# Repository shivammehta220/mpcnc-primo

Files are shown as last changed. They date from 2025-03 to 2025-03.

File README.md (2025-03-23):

# MPCNC Primo

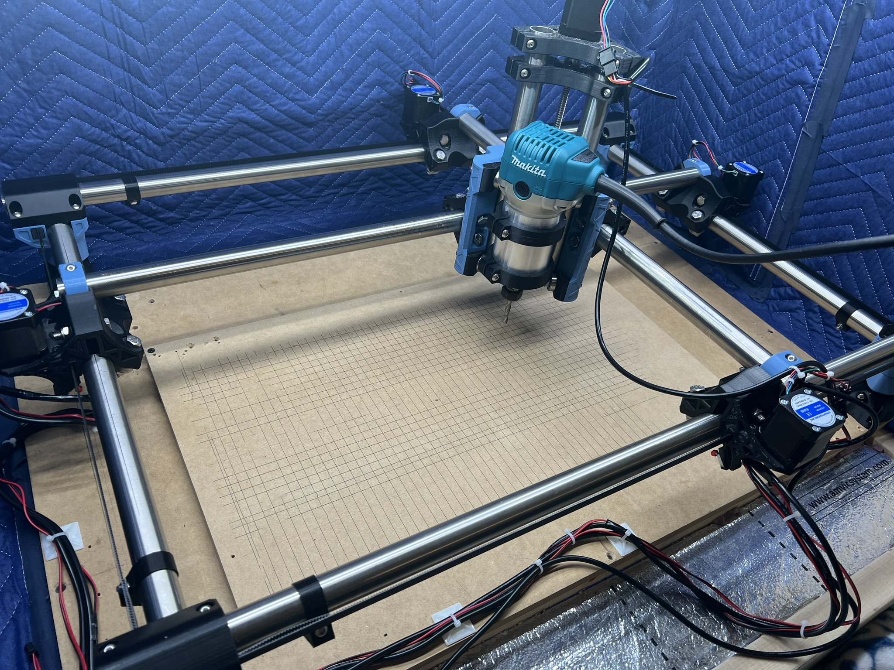
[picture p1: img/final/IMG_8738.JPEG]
Final CNC Build Image

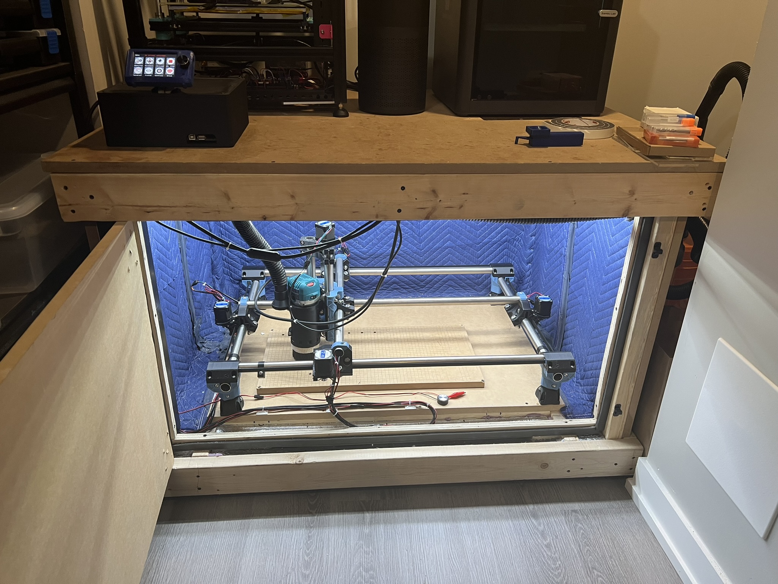
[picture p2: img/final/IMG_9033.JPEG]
Final CNC Build Image


## Table of Contents
- [Description](#description)
- [Table of Resources](#table-of-resources)
- [BOM](#bom)
- [Bits and Settings](#bits-and-settings)
- [Enclosure/Table](#enclosuretable)
- [Dust Management and Dust Shoe](#dust-management-and-dust-shoe)
- [Electronics](#electronics)
- [Build](#build)

---

## Description
This project is my customized version of the [MPCNC Primo](https://www.v1engineering.com/) by V1 Engineering. Within this repository, you will find:
- My unique accessories and modifications.
- Detailed notes on CNC bits and cutting settings.
- A custom-built enclosure/table designed for noise reduction and easy access.
- An electronics box design for convenient maintenance and future upgrades.

The MPCNC (Mostly Printed CNC) is an open-source CNC platform that combines 3D-printed components, off-the-shelf hardware, and commonly available electronics. By customizing the layout, enclosure, and tooling, I’ve tailored this CNC to meet my personal workflow and workspace needs.

---

## Table of Resources
Below is a table of some resources related to this build, including official documentation and helpful community links. Modify or add more links as needed.

| Resource | Link |
|---|---|
| V1 Engineering - MPCNC Primo Docs | [https://www.v1engineering.com/](https://www.v1engineering.com/) |
| Marlin Firmware Repository | [https://github.com/MarlinFirmware/Marlin](https://github.com/MarlinFirmware/Marlin) |
| MPCNC Forum & Community | [https://forum.v1engineering.com/](https://forum.v1engineering.com/) |
| Dust Shoe | [https://grabcad.com/library/mpcnc-primo-dust-shoe-makita-router-1](#) |
| BTT TFT35 v3 TFT Display Case | [https://www.thingiverse.com/thing:4338772](#) |

---

## BOM
Below is the Bill of Materials (BOM) for the MPCNC Primo and the table/enclosure. This includes both the standard hardware from the official MPCNC build, as well as some additional parts I selected for my setup.

| Part | QTY  | Type | Link (if applicable) |
|---|---|---|---|
| Duramic3D PLA+ (Denim Blue & Black) | 2 | Primo Printed Parts | [LINK](https://www.amazon.ca/dp/B08HJ6RML7?ref_=ppx_hzsearch_conn_dt_b_fed_asin_title_3) |
| M8x40mm | 44  | Hardware | [LINK](https://www.amazon.ca/dp/B08595FX34?ref_=ppx_hzsearch_conn_dt_b_fed_asin_title_1&th=1) |
| M8 Locknut | 44 | Hardware | [LINK](https://www.amazon.ca/dp/B0BMX3CBNL?ref_=ppx_hzsearch_conn_dt_b_fed_asin_title_1&th=1) |
| M5x30mm | 60 | Hardware | [LINK](https://www.amazon.ca/iexcell-Thread-Stainless-Socket-Button/dp/B0B5LVMKYY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) |
| M5 Locknut | 60 | Hardware | [LINK](https://www.amazon.ca/dp/B078NNFT93?ref_=ppx_hzsearch_conn_dt_b_fed_asin_title_4&th=1) |
| M3x10mm | 22 | Hardware | [LINK](https://www.amazon.ca/iExcell-Stainless-Socket-Button-Included/dp/B08H2HSPQD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) |
| M2.5x12mm | 8 | Hardware | [LINK](https://www.amazon.ca/iexcell-Thread-Socket-Screws-Finish/dp/B0DDXR7YN7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) |
| NEMA 17 50 oz/in+ | 5 | Electronic  | [LINK](https://www.amazon.ca/dp/B00QEYADRQ?ref_=ppx_hzsearch_conn_dt_b_fed_asin_title_1) |
| Belt GT2 10mm | 1 | Hardware | [LINK](https://www.amazon.ca/dp/B0BYVF35PV?ref_=ppx_hzsearch_conn_dt_b_fed_asin_title_2&th=1) |
| Pulley 16T GT2 10mm (5mm bore) | 4 | Hardware | [LINK](https://www.amazon.ca/dp/B0CD7Y5R7Y?ref_=ppx_hzsearch_conn_dt_b_fed_asin_title_1&th=1) |
| Idler 20T GT2 10mm (5mm bore)  | 8 | Hardware  | [LINK](https://www.amazon.ca/dp/B07P7CF1SZ?ref_=ppx_hzsearch_conn_dt_b_fed_asin_title_2) |
| 24V Power Supply (PSU)  | 1 | Electronic | [LINK](https://www.amazon.ca/dp/B07TTRY6XF?ref_=ppx_hzsearch_conn_dt_b_fed_asin_title_5&th=1) |
| Power Supply Fuse  | 1 | Electronic | [LINK](https://www.amazon.ca/dp/B07Y8DBF7T?ref_=ppx_hzod_title_dt_b_fed_asin_title_0_1) |
| 4-Strand Wires | 1 | Electronic | [LINK](https://www.amazon.ca/dp/B0CLRLJW9K?ref_=ppx_hzsearch_conn_dt_b_fed_asin_title_10&th=1) |
| Bearings | 45 | Hardware | [LINK](https://www.amazon.ca/dp/B00EPNN62M?ref_=ppx_hzsearch_conn_dt_b_fed_asin_title_5&th=1) |
| Leadscrew/Nut | 1 | Hardware | [LINK](https://www.amazon.ca/gp/product/B0981YZ7DN?ie=UTF8&th=1) |
| 5mm to 8mm Coupler  | 1 | Hardware | [LINK](https://www.amazon.ca/gp/product/B011HV6EI2?ie=UTF8&psc=1) |
| SKR Pro | 1 | Electronic  | [LINK](https://www.amazon.ca/BIGTREETECH-high-Frequency-Printer-Control-12864lcd/dp/B07T2RLG2C?th=1) |
| End Stops | 4 | Switch | [LINK](https://www.amazon.ca/dp/B08736NP44?ref_=ppx_hzsearch_conn_dt_b_fed_asin_title_7) |
| BTT TFT | 1 | Electronic  | [LINK](https://www.amazon.ca/BIGTREETECH-Direct-Upgrade-Controller-Motherboard/dp/B07VWGFKLZ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) |
| Makita RT701 | 1 | Router | [LINK](https://www.amazon.ca/gp/product/B00E7D3V4S?ie=UTF8&th=1) |
| Dust Shoe Brush | 1 | Hardware  | [LINK](https://www.amazon.ca/dp/B08M98BRKS?ref_=ppx_hzsearch_conn_dt_b_fed_asin_title_4) |
| M5 Waste Board Nut  | 60 | Hardware | [LINK](https://www.amazon.ca/gp/product/B07D28RKBB?ie=UTF8&th=1) |
| 2x4 | * | Table | [Local Sourcing] |
| 3/4" MDF | * | Table | [Local Sourcing] |
| Hinge | 2 | Table | [Local Sourcing] |
| Door Lock | 2 | Table | [Local Sourcing] |
| Dust Collector | 1 | Collector Unit | [LINK](https://www.amazon.ca/dp/B07XL8X3DG?ref_=ppx_hzsearch_conn_dt_b_fed_asin_title_3&th=1) |
| Dust Bin | 1 | Table | [Local Sourcing] |
| Vacuum | 1 | Table | [LINK](https://www.amazon.ca/Shop-Vac-5985005-Workshop-Gallon-1-Pack/dp/B09FRY4CFV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) |
| Vacuum Hose | 1 | Table | [LINK](https://www.amazon.ca/dp/B00FX36WII?ref_=ppx_hzsearch_conn_dt_b_fed_asin_title_2) |
| Z Endstop | 1 | Electronic | [LINK](https://www.amazon.ca/gp/product/B07Z5X9YHJ?ie=UTF8&psc=1) |

> **Note:** The exact quantities for fasteners (*) will vary based on final frame dimensions and personal enclosure designs.

Below is the BOM of the rails used for my build. The tubes I bought were stainless steel, and I opted for version J (25.4mm). My workspace based off the calculator is 600mm(x) x 330mm(y) x 83mm(z)

| Length (mm/inch) | QTY  | Name | 
|---|---|---|
| 904/35.5 | 2 | x rails, sides | 
| 849/33.25 | 1  | x rail, gantry | 
| 643/25.25 | 2 | y rails, sides |
| 588/23.25 | 1 | y rail, gantry |
| 273/10.75 | 2 | z rails |
| 62/2.5 | 4 | legs |
| 133/5.25 | 1 | leadscrew length |
| 954/37.5 | 2 | Locbelt length along xknut |
| 693/27.25 | 2 | belt length along y |

---

## Bits and Settings
Below is a table of the bits and common settings I use for this CNC project. These values may serve as a good starting point, but always consider your specific material, router performance, and personal safety when finalizing parameters.

| Bit | Material | RPM (Router) | DOC (Depth of Cut) | Stepover |  Feed XY | Feed Z | Notes |
|---|---|---|---|---|---|---|---|
| [SpeTool Carbide Singe Flute End Mill Set, 1/8" Cutting Diamter 1/4" Shank 1/2" Cutting Length,Spiral CNC Router Bit for Aluminum Acrylic](https://www.amazon.ca/gp/product/B0BCK4RWZG/ref=ppx_yo_dt_b_search_asin_title?ie=UTF8&th=1) | MDF | 18,000 -20,000(4) | 1.5 mm to 2 mm | |  15 to 20 mm/s (900 to 1,200 mm/min)| 3 to 5 mm/s (180 to 300 mm/min)| MDF Drill plate |
| [SpeTool UP Cut Spiral Router Bits 1/4 Shank with 1/4 Inch Cutting Diameter ,1-1/4 Inch Cutting Length 3 Inch OVL,Tungsten Carbide - 2 flute](https://www.amazon.ca/SpeTool-Cutting-Diameter-Tungsten-Woodworking/dp/B0B6VNYJZ3) | MDF | 13,500 (2.5) | | |  17mm/s | 3mm/s| waste board |
| [SpeTool Single Flute (O Flute) Spiral End Mill - 1/4inch - 1 Inch Cutting Length - Carbide -UpCut](https://www.amazon.ca/SpeTool-Aluminum-Cutting-Carbide-Acrylic/dp/B083TKN62R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)  | Cast Acrylic | 11k (1.5 )(2.0) | 2D Pocket: 1.59 mm (max rough stepdown), 0.2mm (Finishing stepdown), 2D Contour:1.0mm, 2D Adaptive: 3.8mm Opt. Load 1.5mm | 3.18mm |  15.5mm/s 930mm/min | 4.5mm/s 270mm/min| Pocket/Contour|
| [SpeTool Carbide Singe Flute End Mill Set, 1/8" Cutting Diamter 1/4" Shank 1/2" Cutting Length,Spiral CNC Router Bit for Aluminum Acrylic](https://www.amazon.ca/gp/product/B0BCK4RWZG/ref=ppx_yo_dt_b_search_asin_title?ie=UTF8&th=1) | Cast Acrylic  | 18k (3.1) | 2D Pocket:2.03mm (max rough stepdown), 0.1mm (Finishing stepdown), 2D Contour:1.59mm, 2D Adaptive: 3.18 mm, Opt. Load 0.33mm | 1.59mm |  18mm/s 1080 mm/min | 5.5 mm/s 330mm/min| M4 Bore and Pocket/Contour |
| [SpeTool Flat Nose Double Flute Carbide End Mill 1/32" - 1/8" shank, 1/32" cutting diameter, 5/64" cutting length, 1-1/2" over all length - 2 flute](https://www.amazon.ca/dp/B07S5HX5NS?psc=1&ref=ppx_yo2ov_dt_b_product_details) | Cast Acrylic  | 10k (1) | 0.2mm (max rough stepdown), 0.1mm (Finishing stepdown) | 0.47mm |  10mm/s 600mm/min | 3mm/s 180mm/min| 2mm O-ring pocket |
| [SpeTool 1/16 Inch Cutting Diameter Upcut Spiral Router Bit with 1/4 Inch Shank 1/4 Inch Cutting Length 2 Inch OVL, Solid Carbide Plunge Router Bits CNC Mill for Woodworking](https://www.amazon.ca/dp/B0BJPGH9FR?ref=ppx_yo2ov_dt_b_fed_asin_title&th=1) | Cast Acrylic  | 18k (3.1) | 2D Pocket: 1.14mm(max rough stepdown), 0.1mm (Finishing stepdown), 2D Contour: 0.79mm, 2D Adaptive: 1.59,Opt. Load 0.254mm | 0.79mm (Pocket) |  16.9mm/s 1014mm/min | 5.5 mm/s 330mm/min| |

- **RPM**: Adjust based on material hardness and router capability.
- **DOC**: Deeper cuts may strain the machine; always ensure the rigidity can handle it.
- **Stepover**: Affects finish quality and tool load.
- **Feed Rates**: Experiment with feed rates to optimize cut time vs. cut quality.

---

## Enclosure/Table
The **table folder** in this repo contains drawings and CAD for the custom table/enclosure that houses my MPCNC Primo. This design places the CNC near the ground, allowing the top of the enclosure to function as a sturdy work surface.

- **Structure**: Constructed from 2x4 lumber and 3/4" MDF sheets.
- **Noise Reduction**: Lined with insulation and moving blankets to dampen operational noise.
- **Visibility & Access**: Integrated LEDs for internal lighting. The wasteboard is easy to remove for cleaning or replacement. 
- **Electronics Box**: Attached for quick maintenance or part upgrades.
- **Ergonomics**: You can operate the CNC from a low chair or stool. The top surface comfortably supports multiple 3D printers or other equipment.

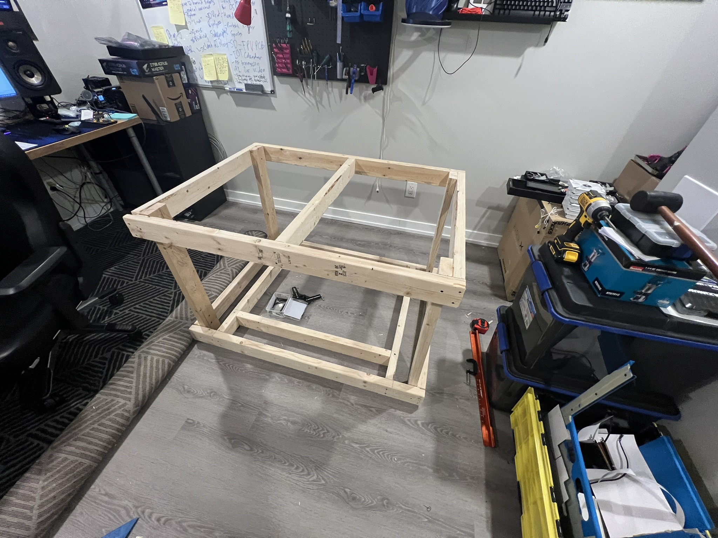
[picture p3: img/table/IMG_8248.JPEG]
Table Build Image

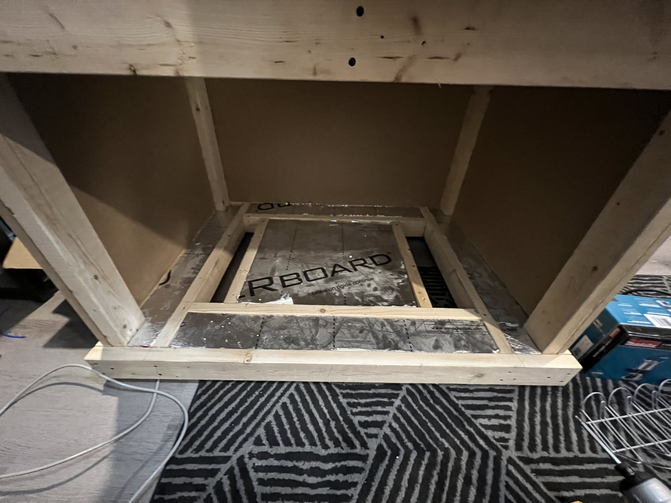
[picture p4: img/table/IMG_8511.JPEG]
Table Build Image

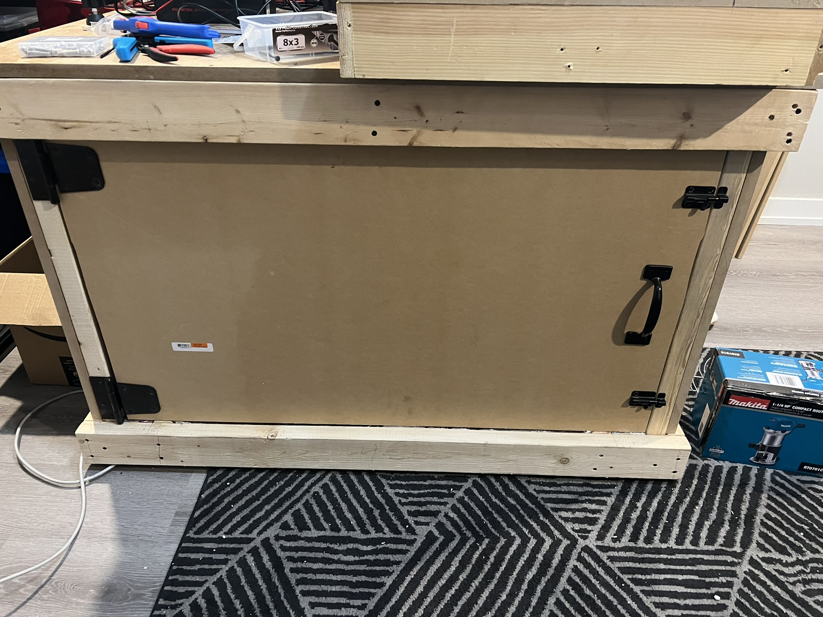
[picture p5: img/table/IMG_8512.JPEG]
Table Build Image

> **Tip**: Consider additional bracing if you plan to mount heavy equipment on the tabletop. Also, be mindful of ventilation and dust extraction routing.

---

## Dust Management and Dust Shoe
The dust shoe I used is made by **[Alex Gryson](https://grabcad.com/library/mpcnc-primo-dust-shoe-makita-router-1/details?folder_id=10605725)**, which is designed to:
- Easily swap out bits without removing the entire shoe.
- Retain the machine’s full cutting area (minimal intrusion on cutting space).

Within the `STL` folder:
- **Vacuum Hose Adapters**: Connect the dust shoe to the main vacuum line.  
- **Quick-Connect Adapter**: Allows my shop-vac to disconnect easily for other workshop tasks.

**Dust Collection Path:**
1. The main hose runs through the side of the enclosure.
2. An internal adapter connects it to my dust collector/shop-vac.
3. A quick-connect fitting streamlines swapping the vacuum from CNC to other tools.

---

## Electronics
Inside the `STL` folder, you will also find the **electronics box** model:
- **SKR Pro + PSU**: Mounted in a secure, ventilated enclosure.
- **Wiring Pass-Through**: There is a dedicated hole for cables to pass from the box to the CNC’s underside.
- **TFT Display**: The top panel includes mounts for a TFT display case. This positions your control interface at a convenient height.

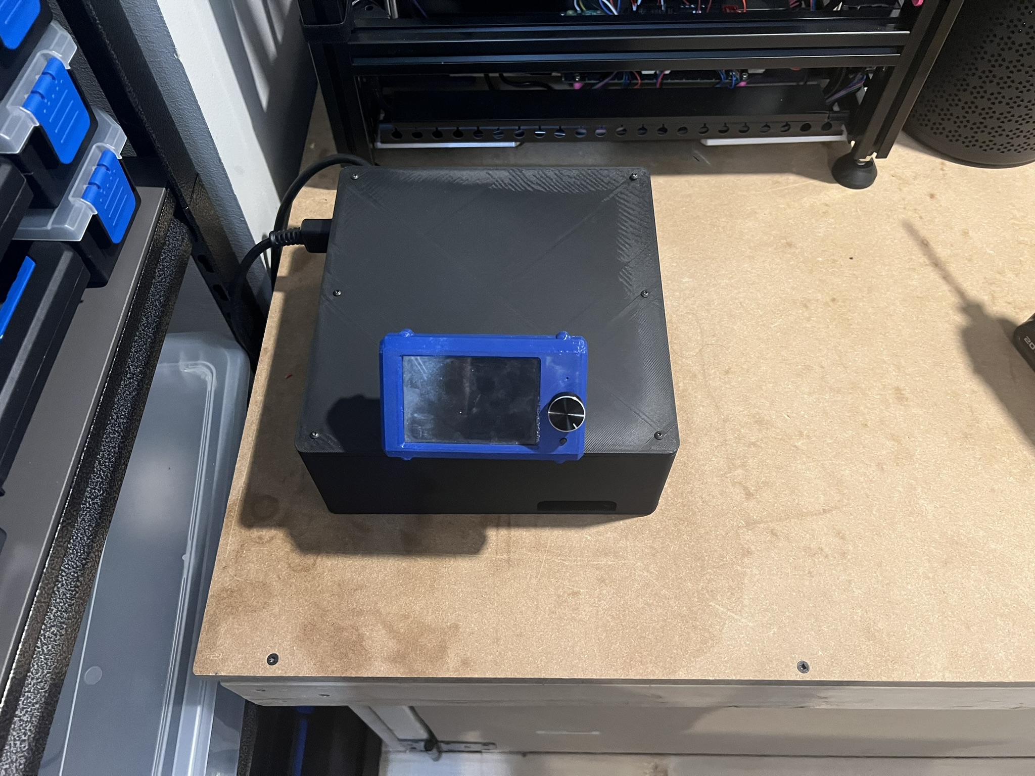
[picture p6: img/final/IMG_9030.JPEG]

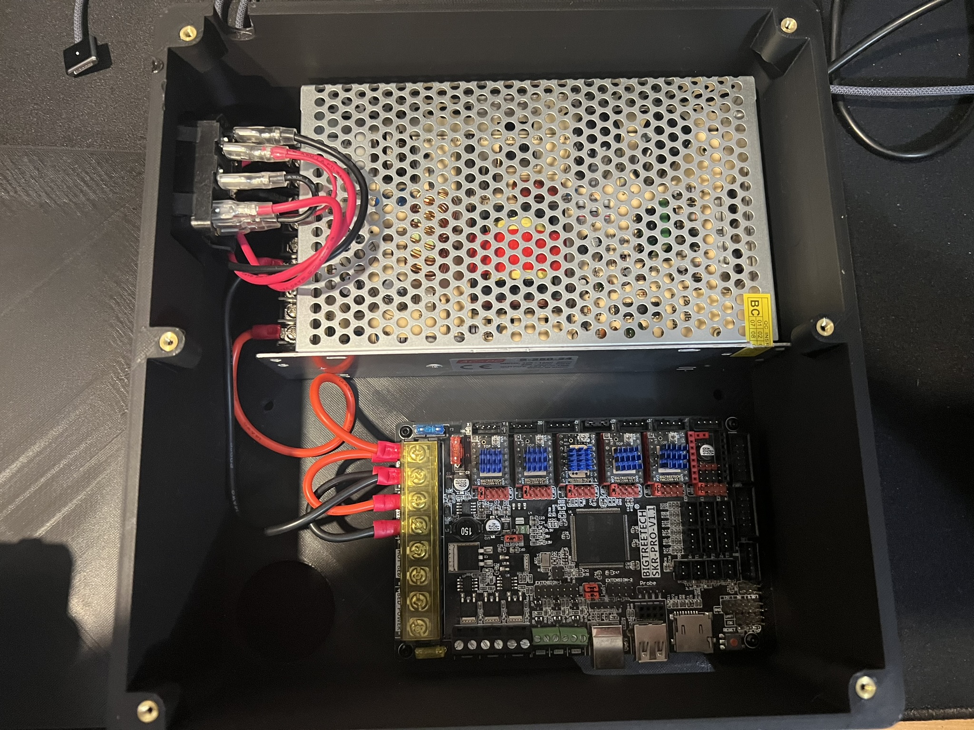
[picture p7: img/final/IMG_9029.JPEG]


> **Note**: Proper cable management (e.g., drag chains, cable ties) will enhance safety

---

## Build
The mechanical assembly was performed according to the official [V1 Engineering MPCNC Docs](https://www.v1engineering.com/). I followed their recommended steps for:
- **Frame Assembly**: Printing and assembling the core, gantries, belt system, and tensioning.
- **Firmware Setup**: Using [Marlin Firmware](https://github.com/MarlinFirmware/Marlin) on the SKR Pro board.
- **Router Mounting**: Securing the Makita RT701 for easy tool changes and consistent performance.

For a detailed walkthrough of my build and the modifications I applied, see the individual subfolders in this repository:
- **Hardware Mods** (Custom brackets, pen holders, dust shoe adapters).
- **Firmware** (Configuration files, custom macros).
- **Enclosure** (Table design, acoustic treatments).

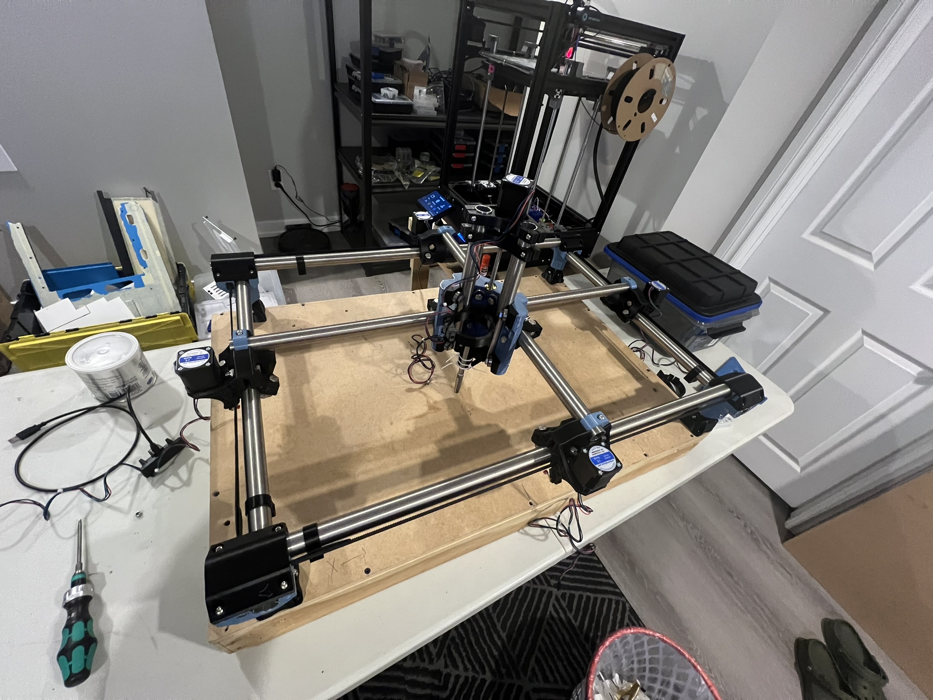
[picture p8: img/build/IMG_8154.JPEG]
Build Image

---

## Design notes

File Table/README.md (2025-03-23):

# Table Enclosure CAD and Drawings  

This directory contains the CAD files and drawings for the enclosure of the MPCNC Primo table.
## Contents  
- **CAD Files**: 3D models of the enclosure components.  
- **Drawings**: Detailed technical drawings with dimensions and specifications.  

## Usage  
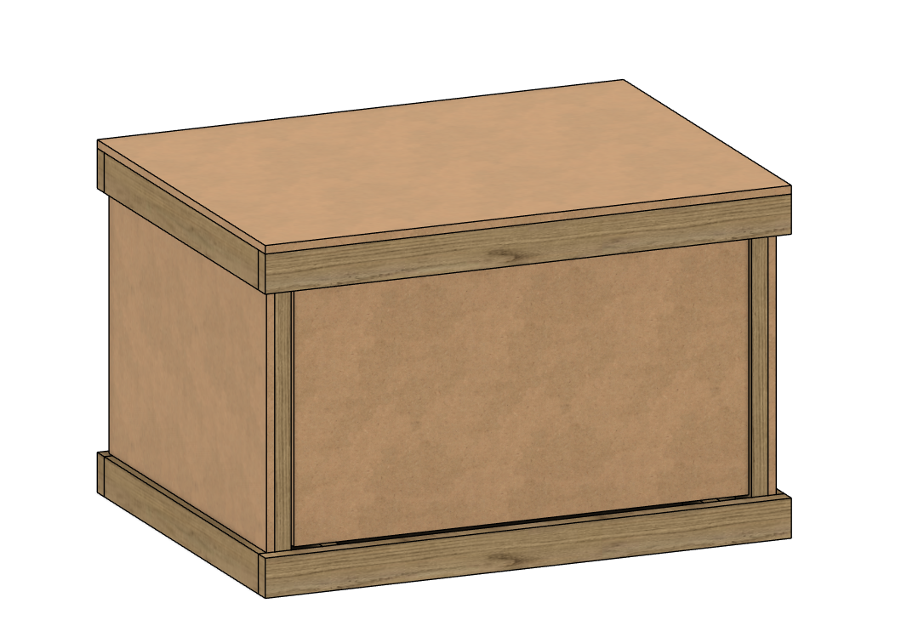
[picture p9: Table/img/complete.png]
Table
 
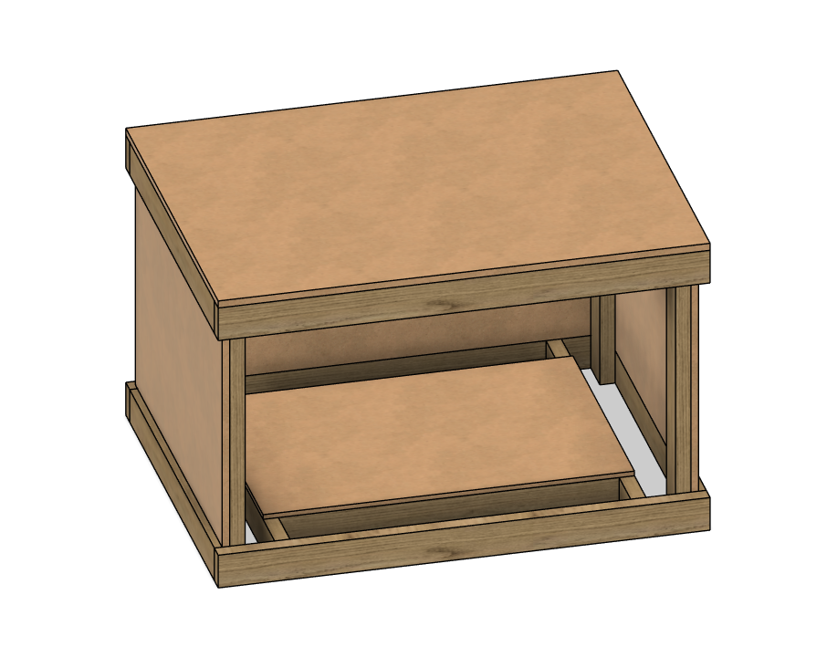
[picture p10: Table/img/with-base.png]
Table


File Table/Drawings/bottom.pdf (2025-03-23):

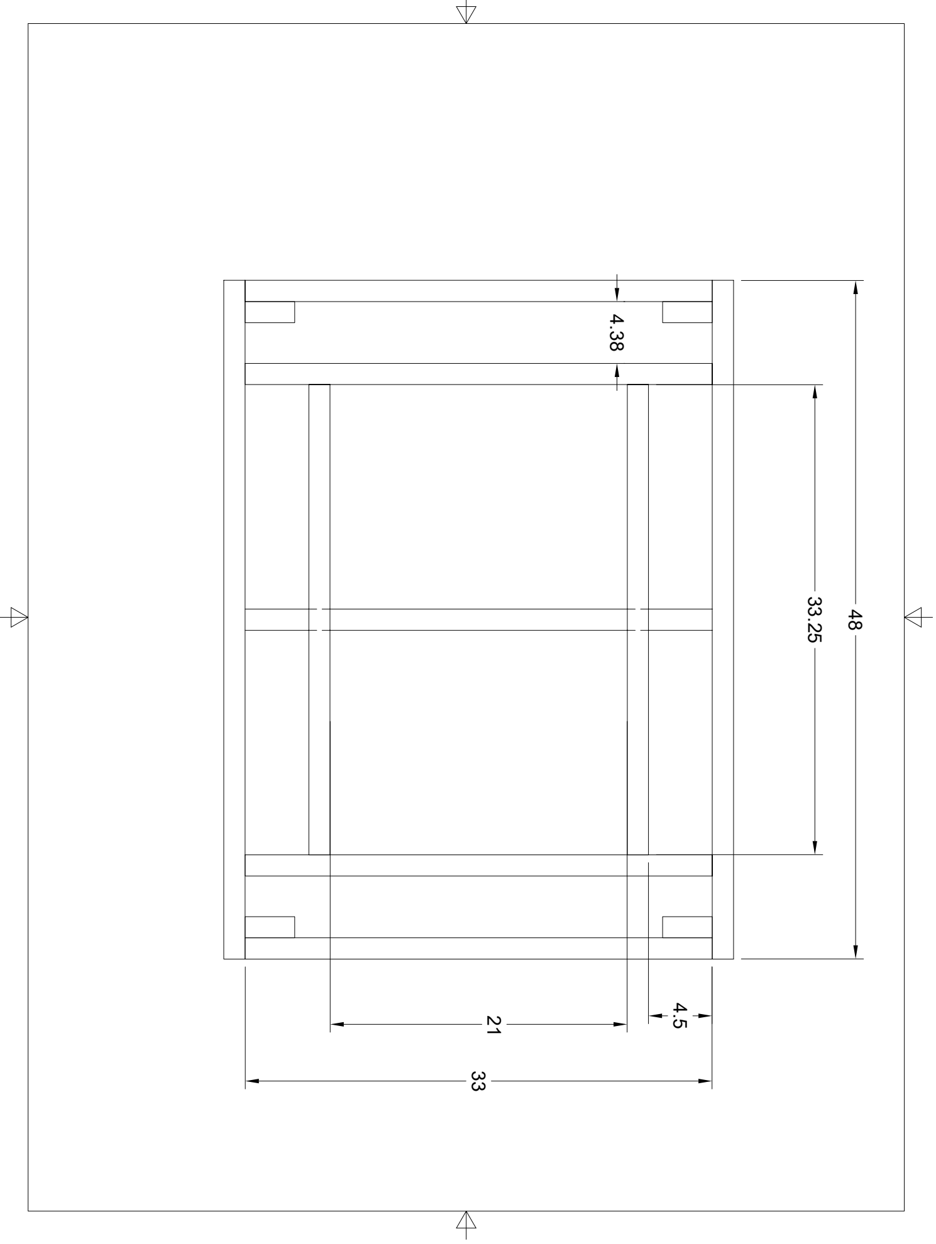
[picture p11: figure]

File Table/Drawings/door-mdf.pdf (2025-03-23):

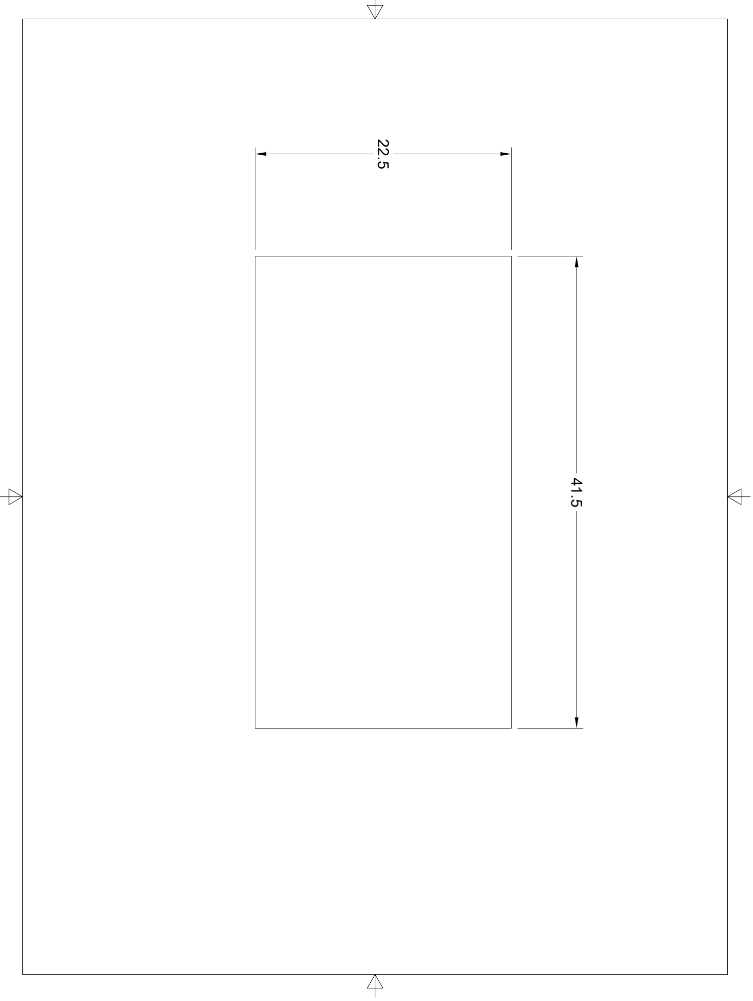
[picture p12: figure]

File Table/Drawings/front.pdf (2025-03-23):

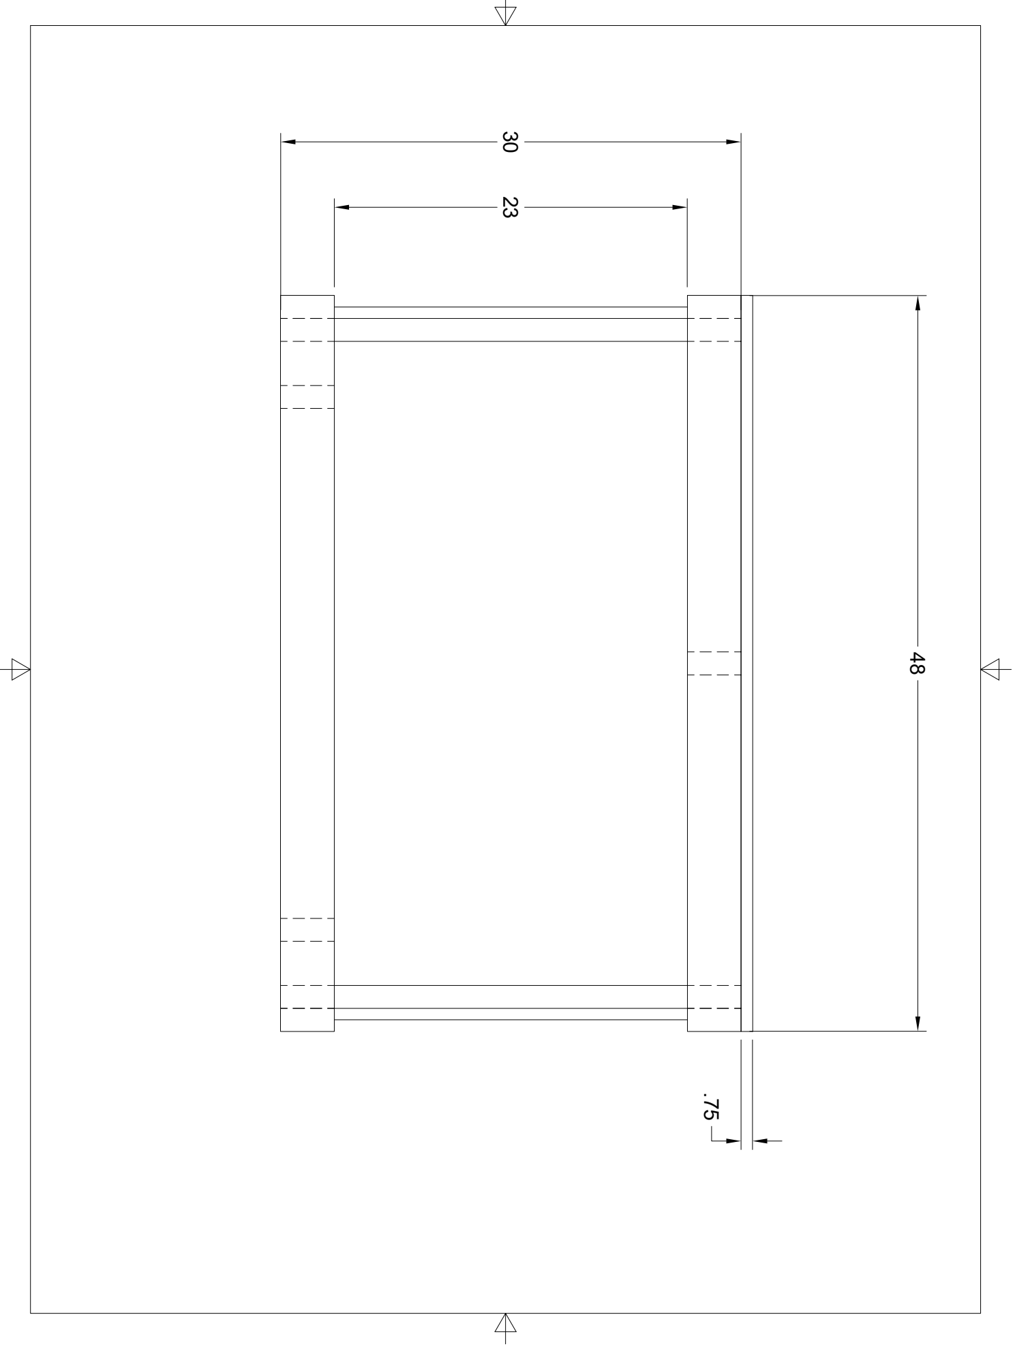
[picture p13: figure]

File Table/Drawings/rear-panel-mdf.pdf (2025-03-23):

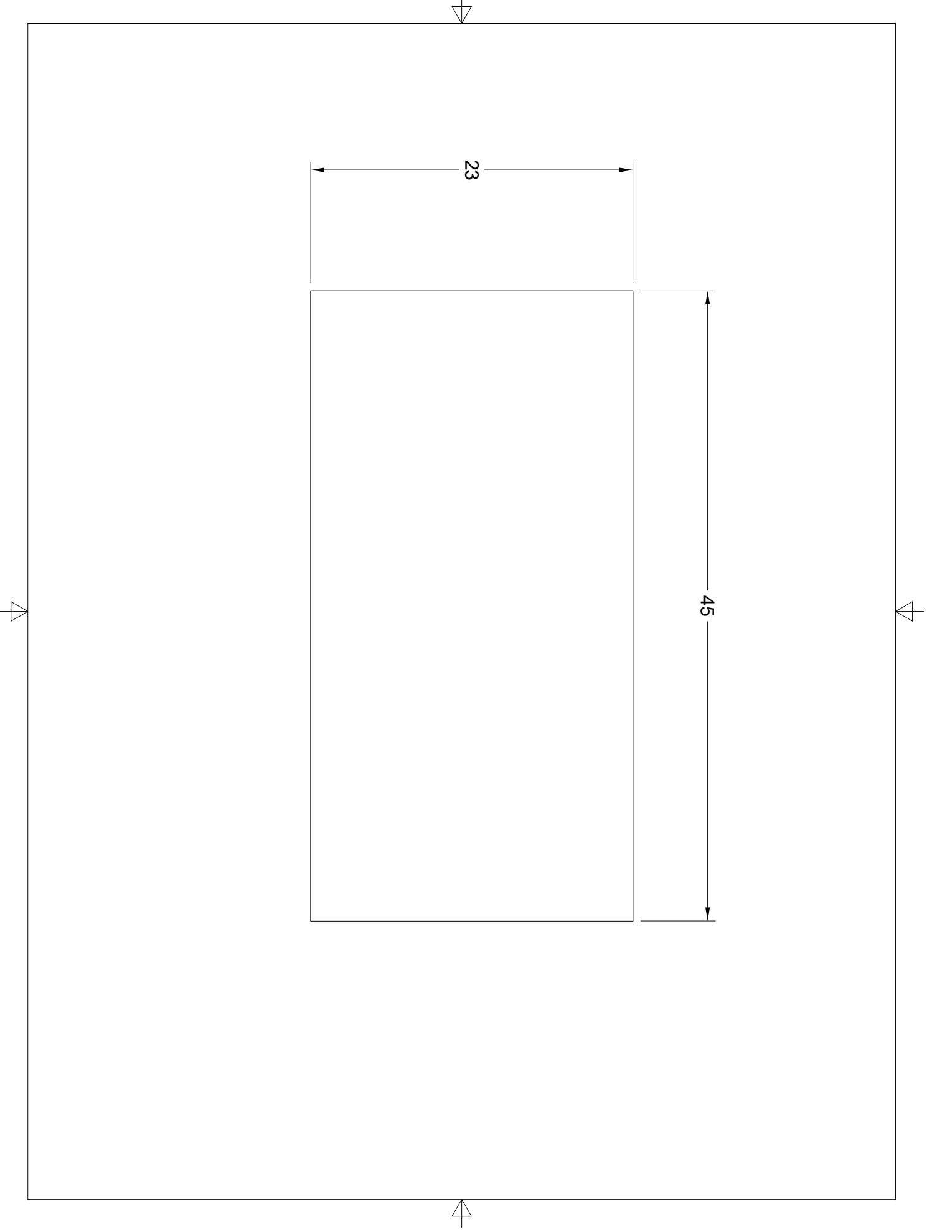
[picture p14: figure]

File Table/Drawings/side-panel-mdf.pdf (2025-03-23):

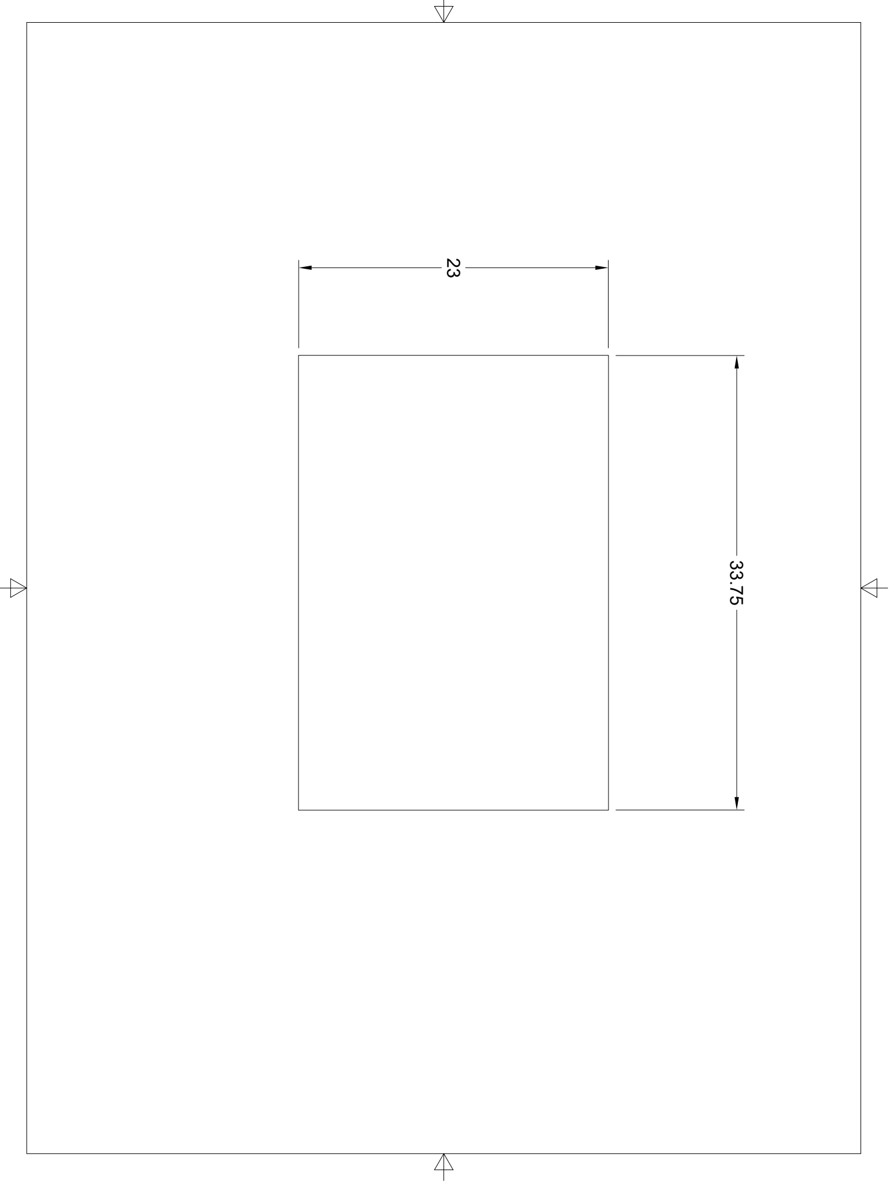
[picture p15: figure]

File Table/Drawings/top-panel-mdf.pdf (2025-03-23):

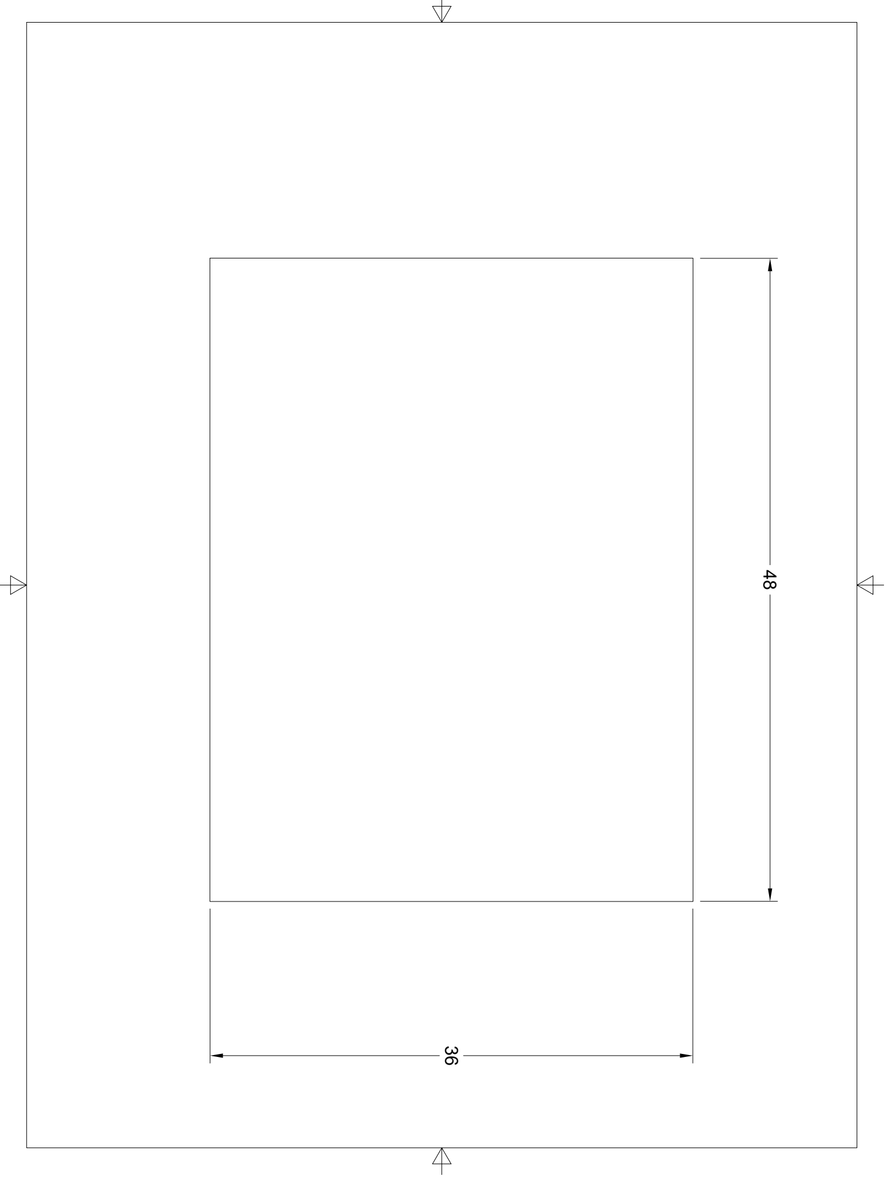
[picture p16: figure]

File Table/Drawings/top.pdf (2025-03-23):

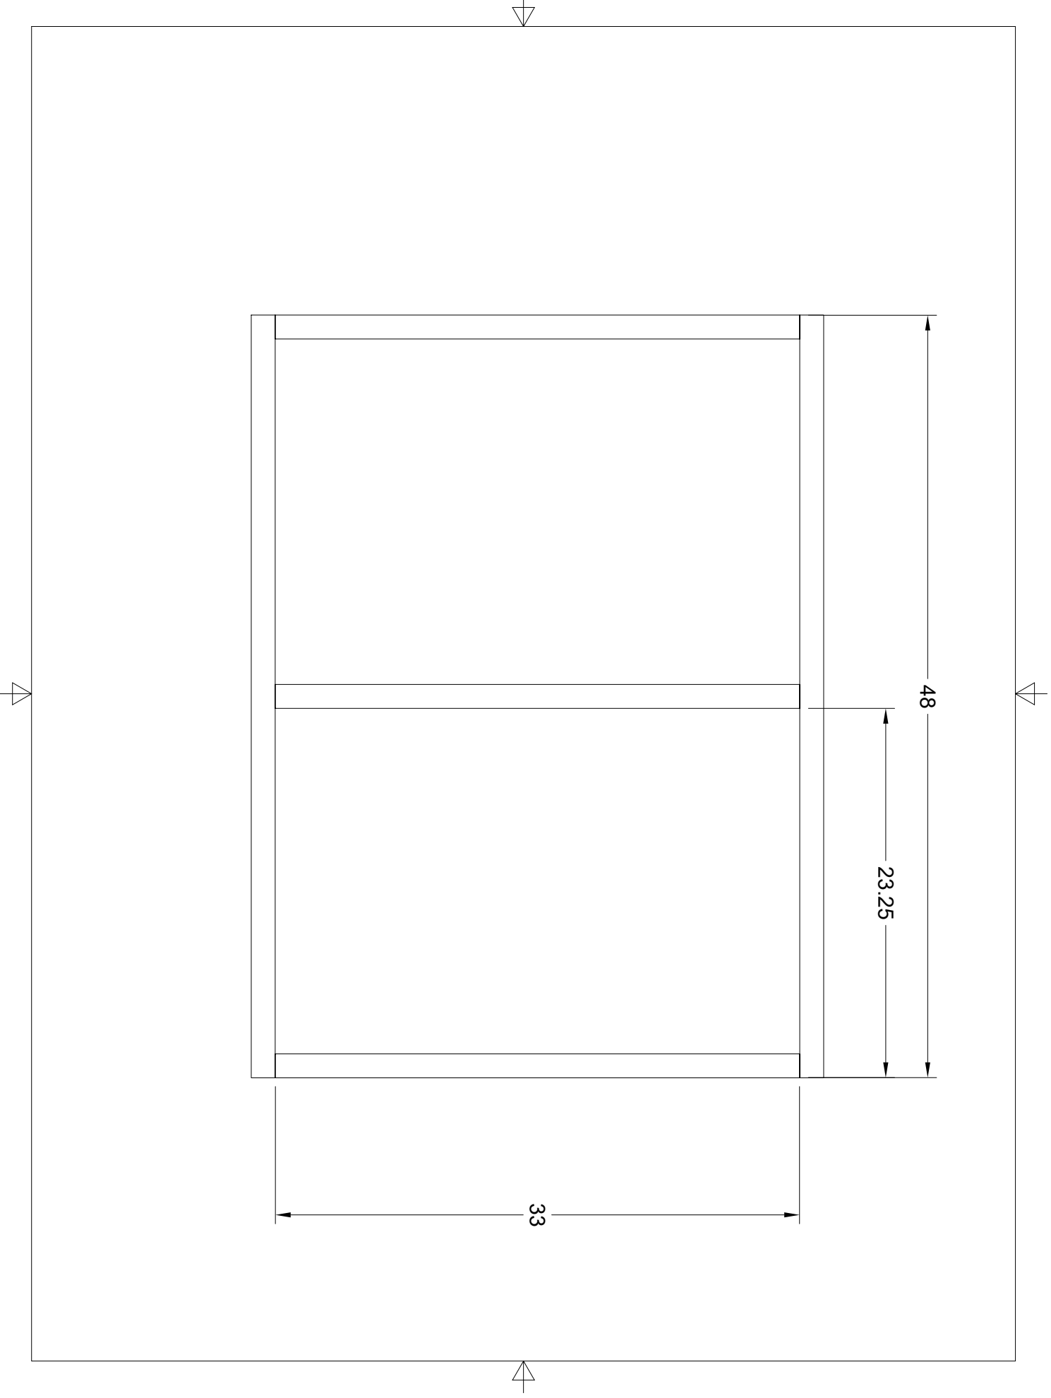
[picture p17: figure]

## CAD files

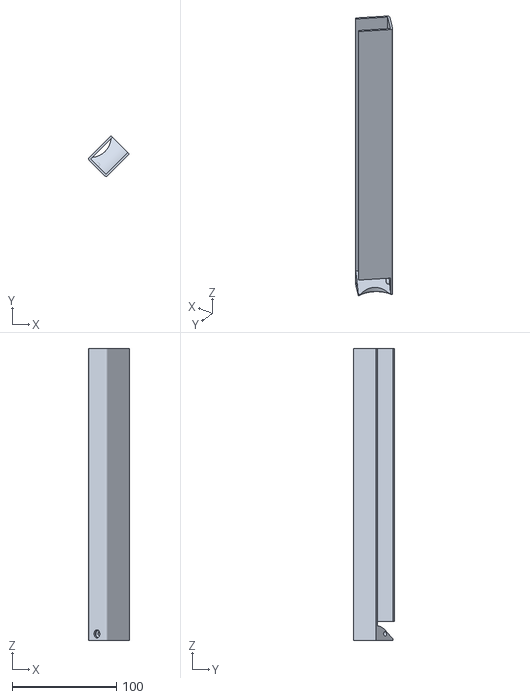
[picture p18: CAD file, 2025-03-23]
STL/Dust-Shoe/Tube_Main.stl
39.1 x 39.1 x 280.0

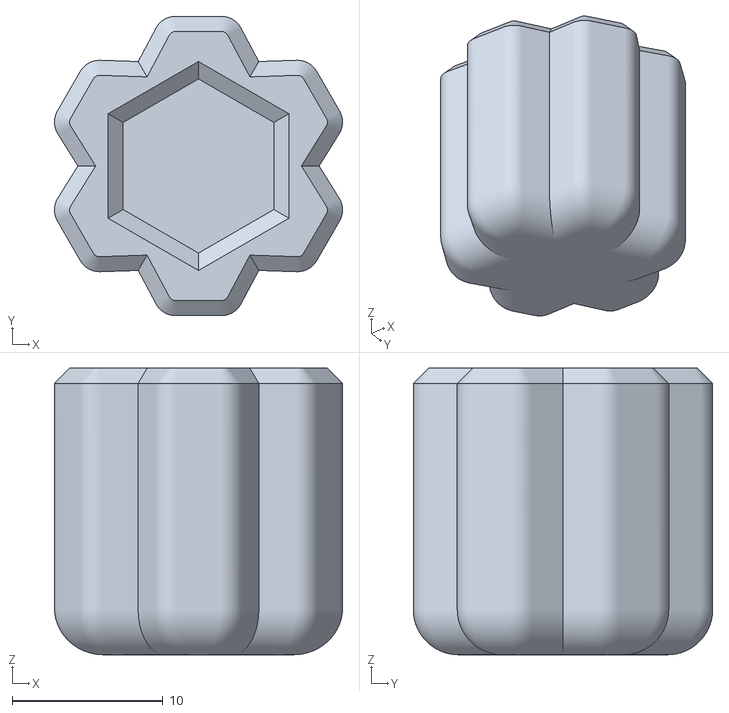
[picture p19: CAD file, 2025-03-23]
STL/Dust-Shoe/M6_Knob.stl
19.1 x 19.9 x 19.0

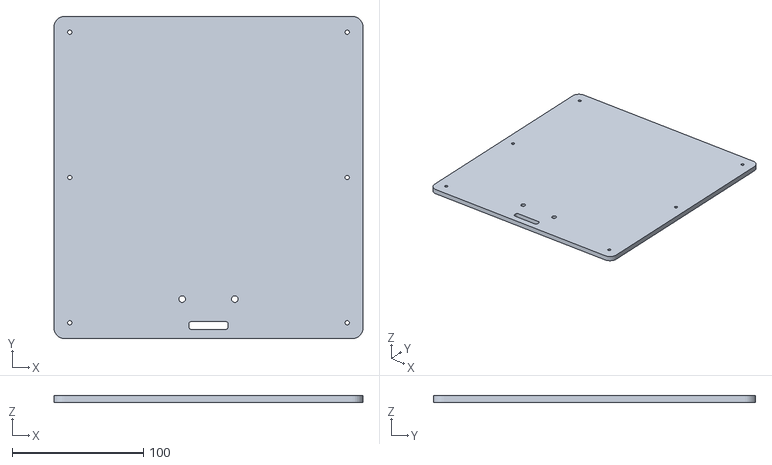
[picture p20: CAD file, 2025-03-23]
STL/Electronics/Lid.stl
235.0 x 245.0 x 5.00

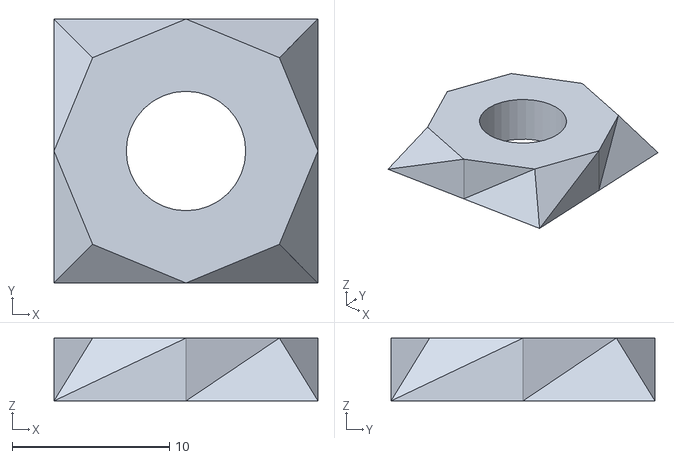
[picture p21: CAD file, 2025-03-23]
STL/TFT-Mount/Box for BigTreeTech TFT35 v3.0 - 4338772/files/BTT_TFT35_v3.0_Box_Encoder.stl
16.8 x 16.8 x 4.00

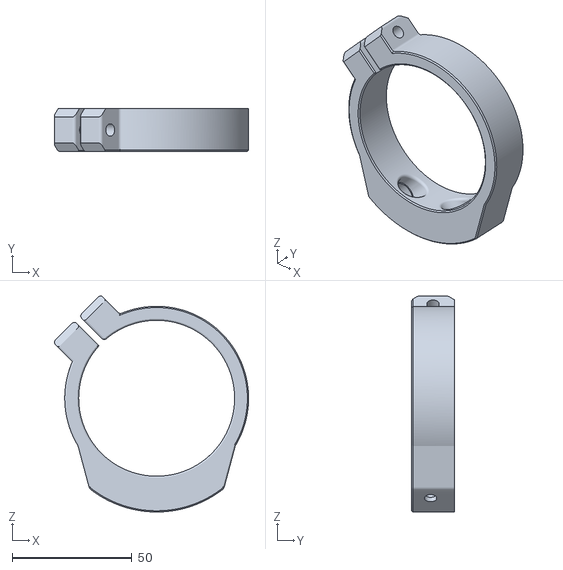
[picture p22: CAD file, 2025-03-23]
STL/Tool-Mounts/makita-rt700-top.stl
81.0 x 18.0 x 90.1

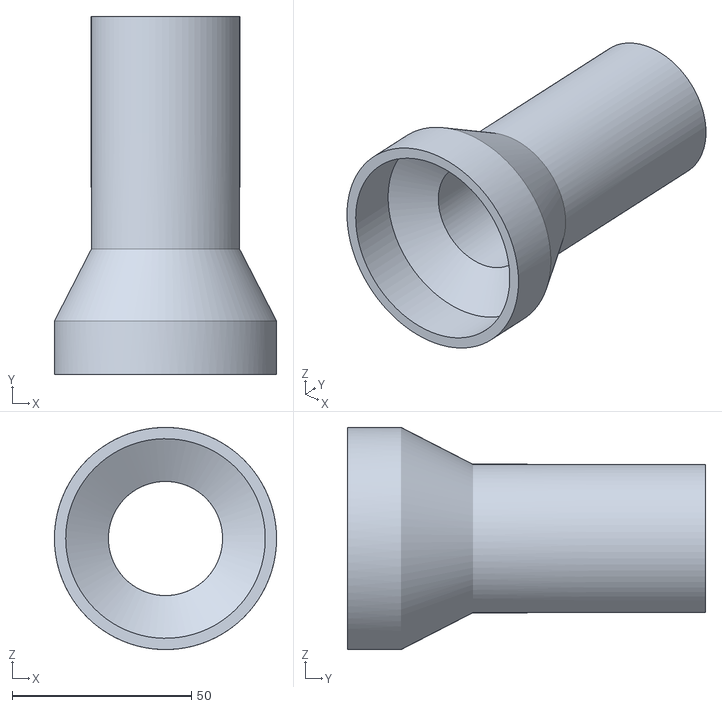
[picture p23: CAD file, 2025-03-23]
STL/Vacuum-Adapter/Vaccum Adapter v1.stl
62.0 x 100.0 x 62.0

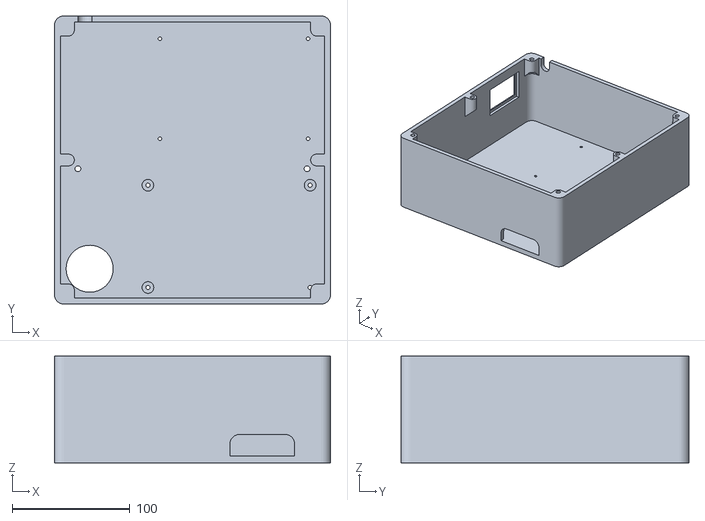
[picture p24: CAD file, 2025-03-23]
STL/Electronics/Base.stl
235.0 x 245.0 x 91.0

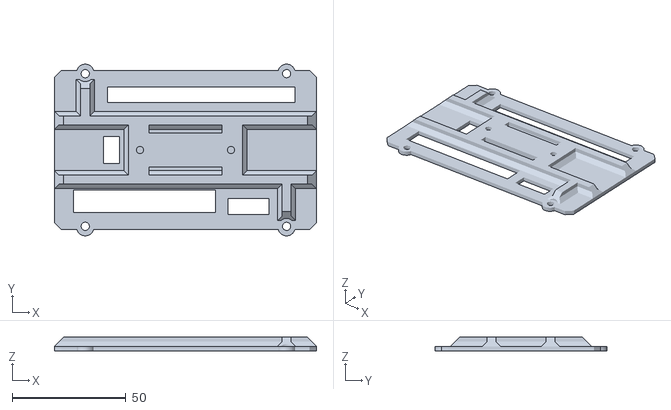
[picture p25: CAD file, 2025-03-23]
STL/TFT-Mount/Box for BigTreeTech TFT35 v3.0 - 4338772/files/BTT_TFT35_v3.0_Box_Back.stl
115.0 x 75.4 x 6.00

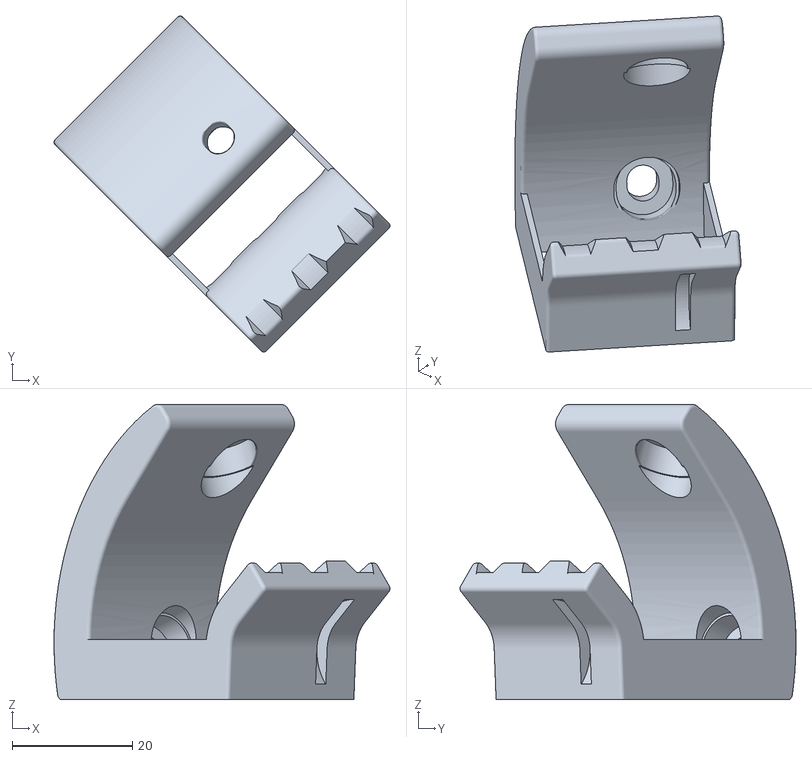
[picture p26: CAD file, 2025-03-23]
STL/Tool-Mounts/knife_pen_mount.stl
55.9 x 55.9 x 49.1

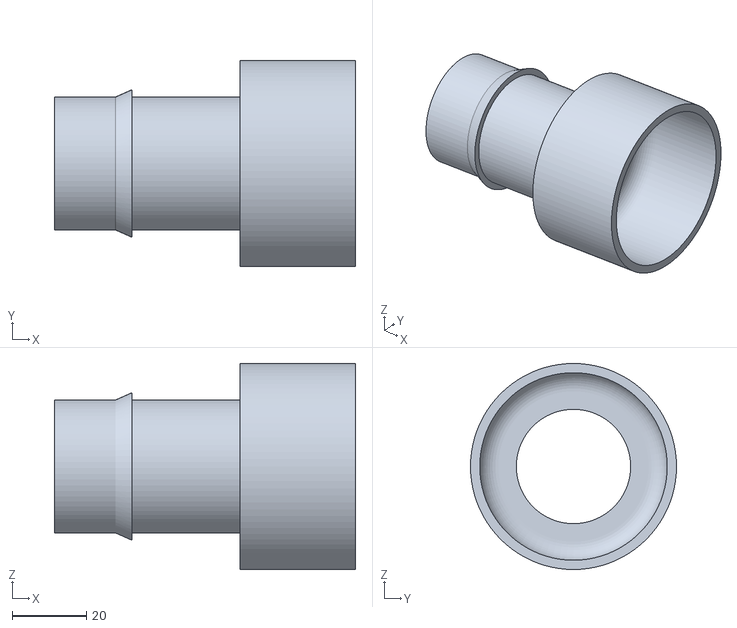
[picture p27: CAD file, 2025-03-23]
STL/Vacuum-Adapter/CNC to Dust v2.stl
81.1 x 55.5 x 55.5

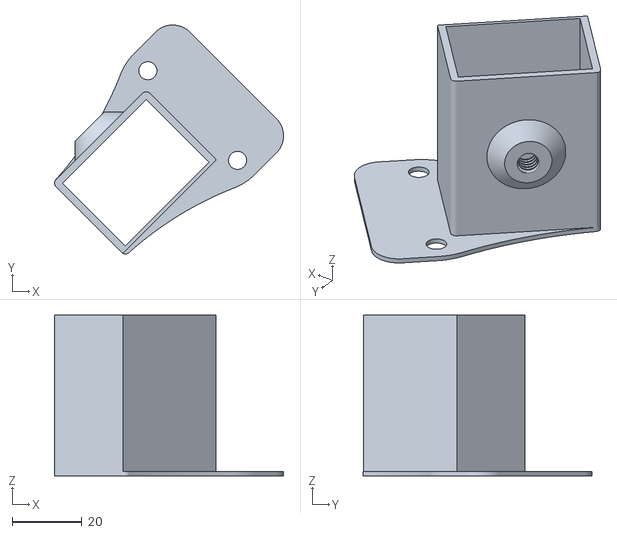
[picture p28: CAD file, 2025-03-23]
STL/Dust-Shoe/Bracket_Lower.stl
65.9 x 65.9 x 46.2

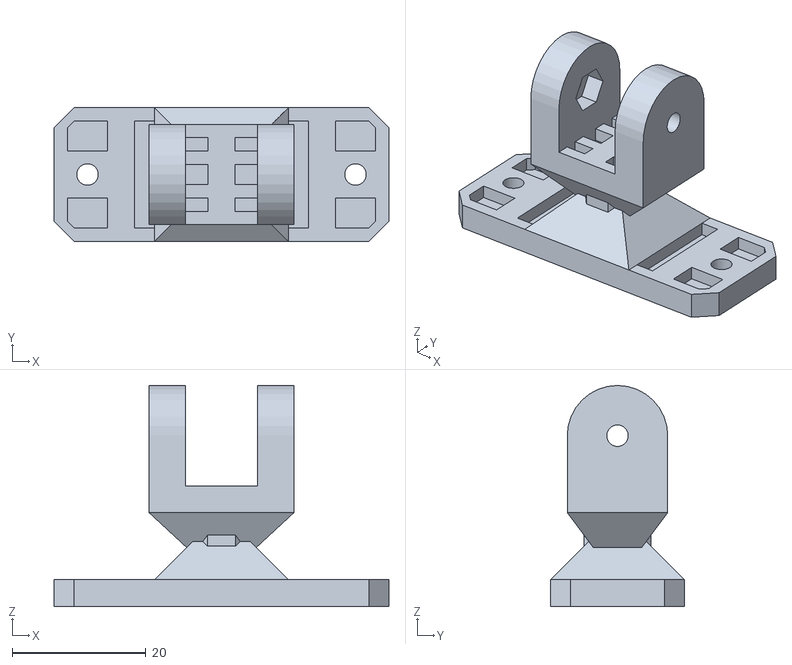
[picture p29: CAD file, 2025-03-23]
STL/TFT-Mount/Box for BigTreeTech TFT35 v3.0 - 4338772/files/BTT_TFT35_v3.0_Box_Half_Leg.stl
50.0 x 20.0 x 33.0

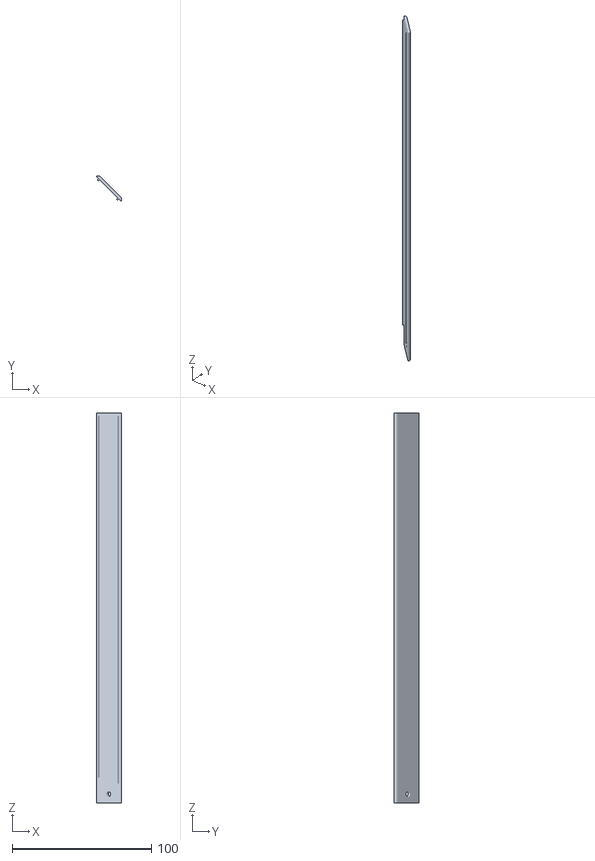
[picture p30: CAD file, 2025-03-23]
STL/Dust-Shoe/Tube_Cover.stl
18.3 x 18.3 x 280.0

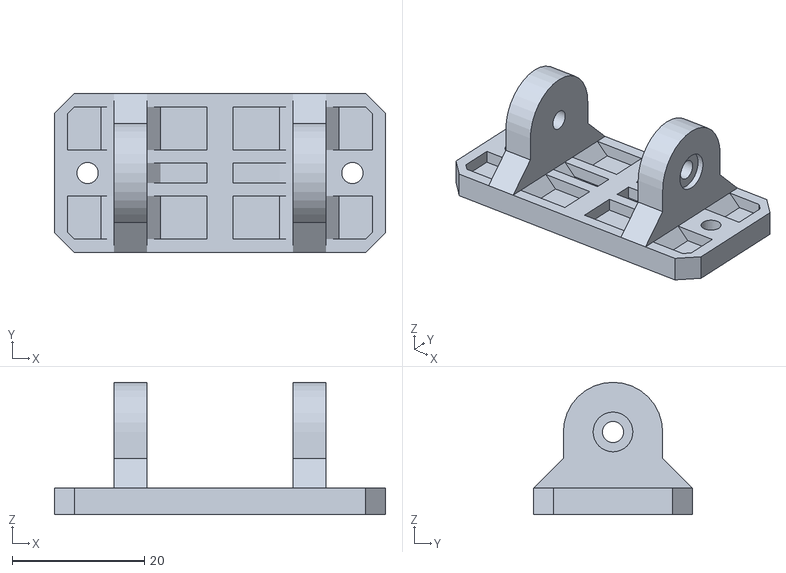
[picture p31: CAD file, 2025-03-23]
STL/TFT-Mount/Box for BigTreeTech TFT35 v3.0 - 4338772/files/BTT_TFT35_v3.0_Box_Holder.stl
50.0 x 24.0 x 20.0

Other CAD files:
STL/Dust-Shoe/Boot_MakitaRT0700x.stl
STL/TFT-Mount/Box for BigTreeTech TFT35 v3.0 - 4338772/files/BTT_TFT35_v3.0_Box_Leg.stl
STL/Dust-Shoe/VacuumAdapter_35mm.stl
STL/TFT-Mount/Box for BigTreeTech TFT35 v3.0 - 4338772/files/BTT_TFT35_v3.0_Box_Front.stl
STL/Dust-Shoe/Bracket_Upper.stl
STL/Dust-Shoe/Bristles.stl
Table/Table v3.f3d

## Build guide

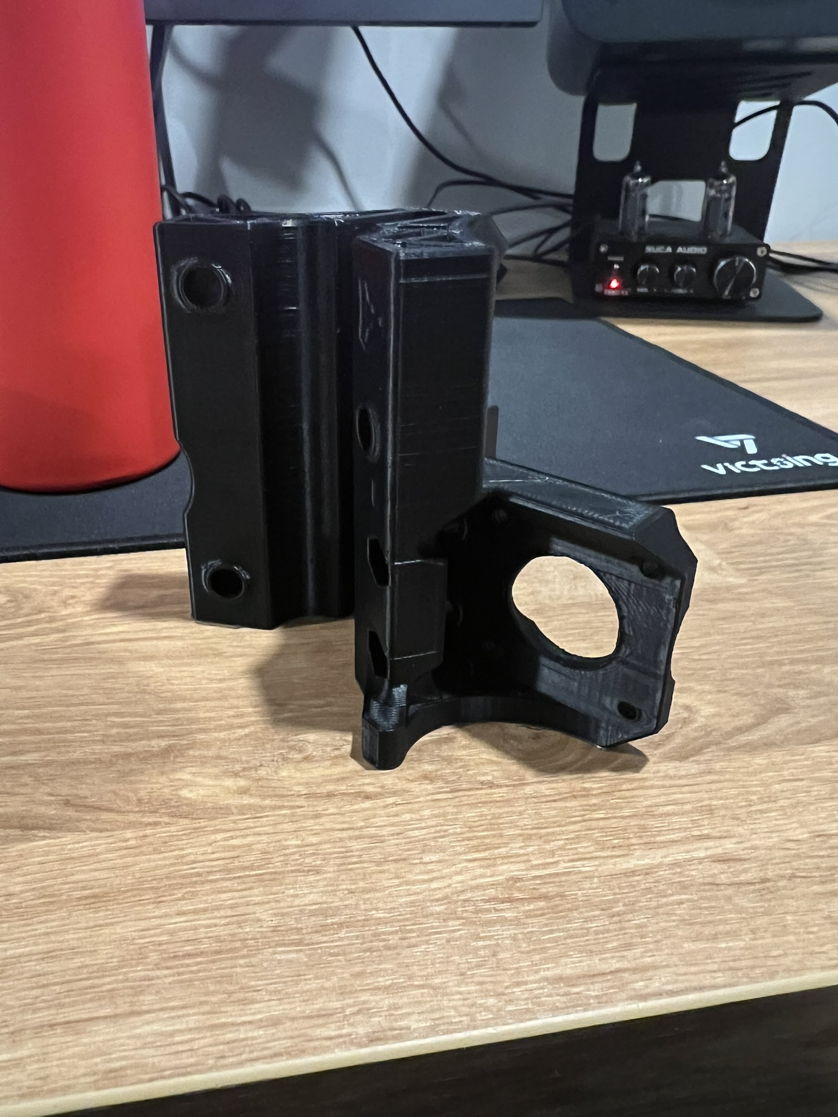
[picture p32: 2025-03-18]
img/build/IMG_8132.JPEG

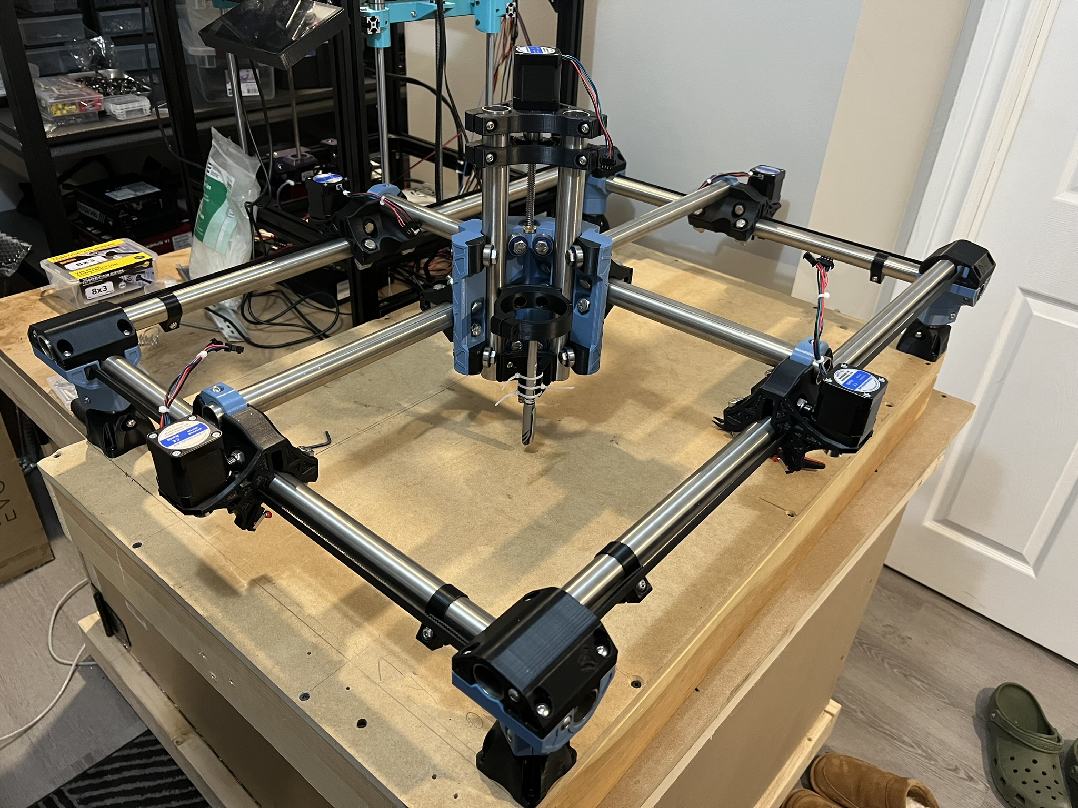
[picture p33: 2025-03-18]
img/build/IMG_8517.JPEG

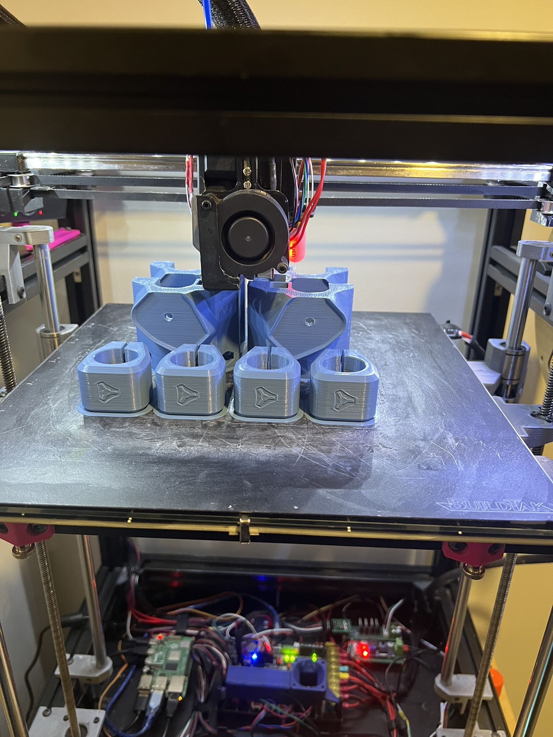
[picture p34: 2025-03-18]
img/build/IMG_8073.JPEG

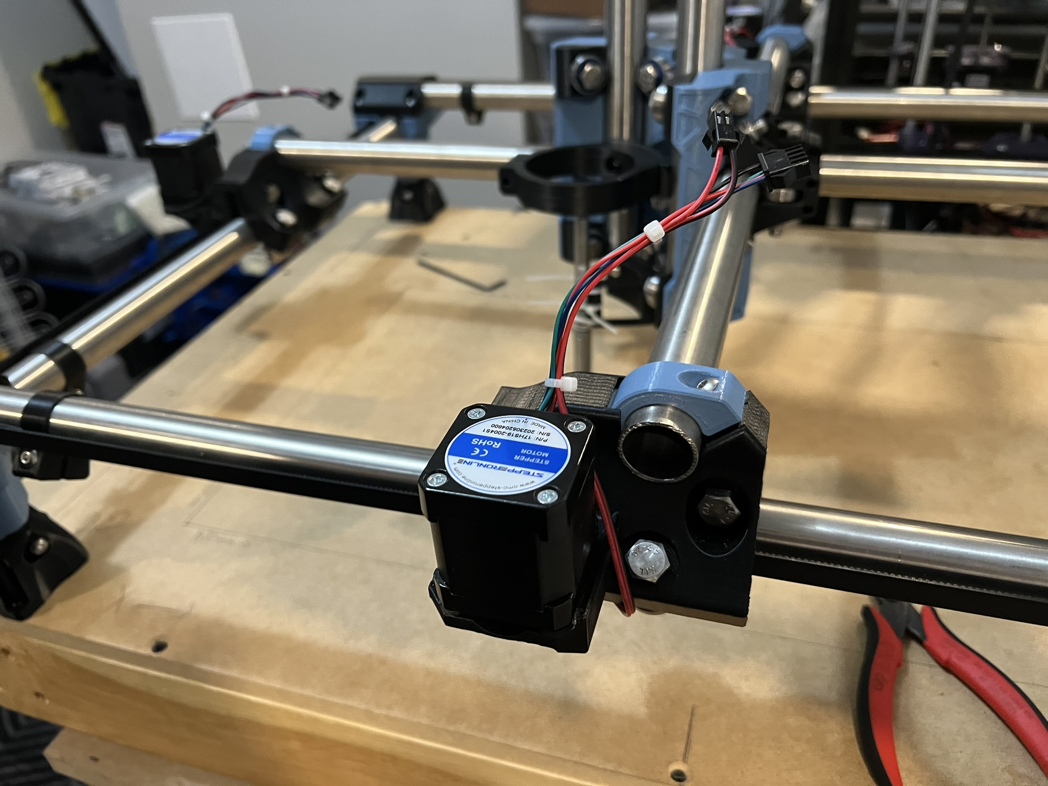
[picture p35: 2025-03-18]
img/build/IMG_8519.JPEG

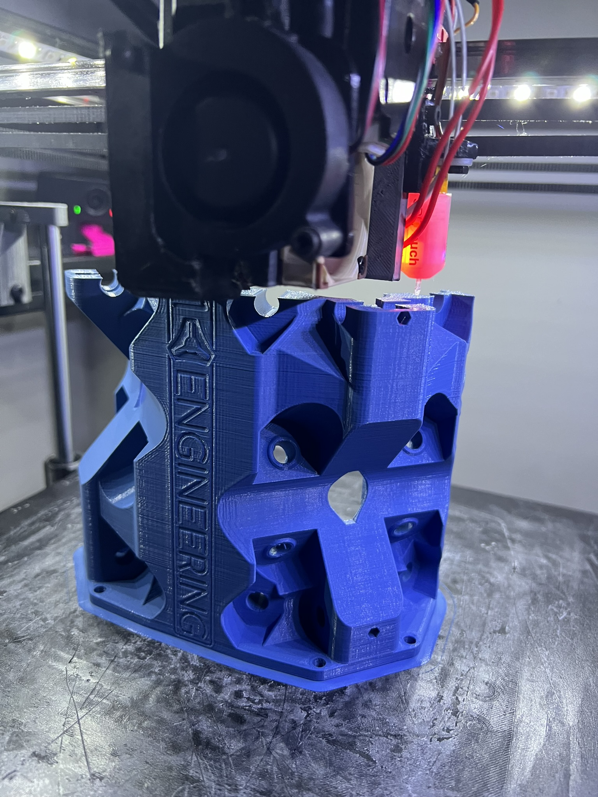
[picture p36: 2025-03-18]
img/build/IMG_8084.JPEG

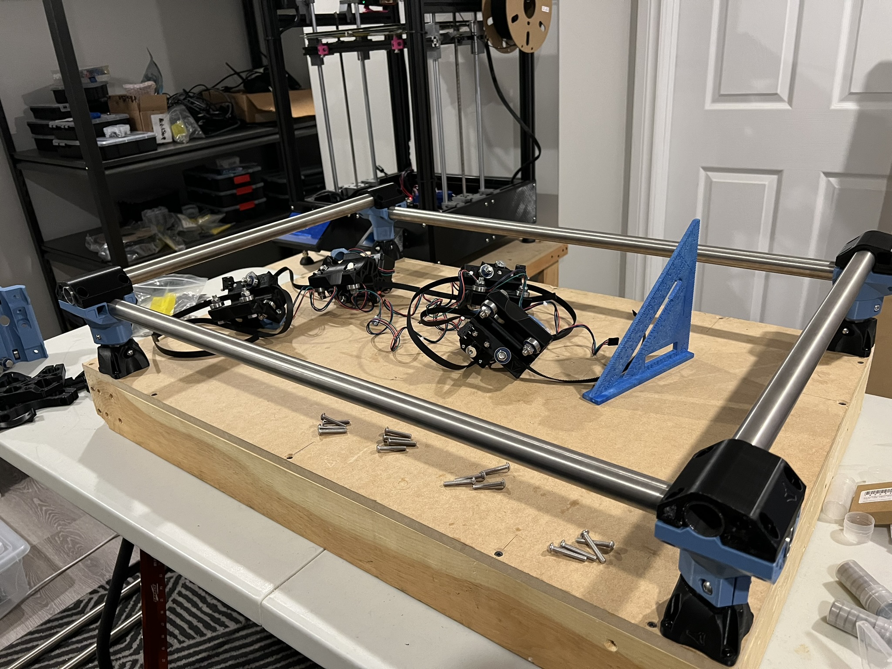
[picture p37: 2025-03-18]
img/build/IMG_8144.JPEG
